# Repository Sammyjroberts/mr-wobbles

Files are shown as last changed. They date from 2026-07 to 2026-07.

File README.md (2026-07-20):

# Mr. Wobbles: a self-balancing two-wheel robot



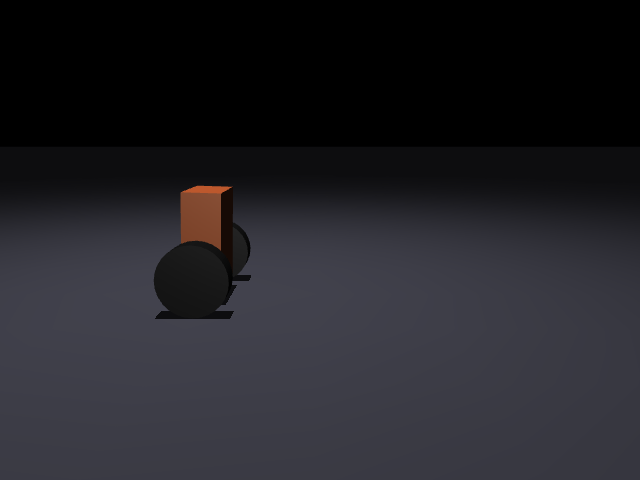
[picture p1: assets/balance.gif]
Mr. Wobbles balancing in simulation, taking a shove and recovering


*MuJoCo sim: the robot settles upright, takes a sideways shove at ~1.5 s, lunges ~27 cm to
catch itself, and drives back to center. Peak tilt during recovery ~3°. The controller is
the LQR designed in this repo, flying on the encoder + IMU signal path; render it yourself
with `scripts/record_gif.py`.*

Mr. Wobbles balancing on the bench (https://youtu.be/HPvMnAkXYeM)

*The real robot.* ▶ <a href="https://youtu.be/HPvMnAkXYeM" target="_blank" rel="noopener noreferrer">Watch on YouTube</a>

An inverted-pendulum robot built from first principles: the controller isn't tuned by
hand on the bench; it's **designed against the real machine**. Physical parameters are
derived from the printed chassis (mass and center of mass pulled straight from the STL)
plus component datasheets, fed into a linearized model, and an optimal (LQR) controller
is solved offline. The same parameters generate the MuJoCo validation plant, so the sim
and the design can never silently disagree.

Python does the physics and control design; the on-robot firmware (Rust + Embassy on an
RP2350 / Pico 2 W) balances the real robot and consumes the gains this repo produces — see
`firmware/`.

---

## The finding that shaped the design

The chassis looks tall and light, so intuition says the center of mass is high and the
robot falls slowly. It's the opposite. **Two 100 g gearmotors sit right on the wheel axle**,
and they drag the CoM down hard. Computed from the actual STL and datasheet masses:

| quantity | value |
|---|---|
| shell mass (from STL, PETG) | 176 g |
| pole / body mass | 511 g |
| total mass (with onboard battery) | 621 g |
| **L, CoM height above the axle**  | **50.8 mm** |

A naive guess put L near 90 mm; the real number is a fraction of that. A low CoM means a
short pendulum, which means a *fast-falling, twitchy* robot that demands a quicker control
loop and leaves less margin. The concrete design response is built into the chassis itself:
**carry the mass high.** The [v4 box-on-K-legs chassis](cad/gen_chassis.py) does this on
purpose — a boxy enclosure rides high on two braced K-legs, so the shell mass sits ~74 mm
above the axle and the electronics + battery nest inside it — so L lands at
**51 mm** instead of the ~29 mm of the old open flat plate, *even after* adding an 85 g battery
the tethered version never carried. Cutting the cord costs mass; standing it up on legs buys
back a longer, more forgiving pendulum. (These numbers regenerate from the STL via
`uv run balancer-params`, which also rewrites `outputs/physical_summary.txt`, so they can't go
stale against the printed chassis.)

This is the whole point of deriving parameters instead of guessing them: the hard part of
the problem was invisible until the numbers were real.

---

## How it works

```
robot_params.py   physical truth  →  mass, CoM, and L straight from the STL + datasheets
      │
      ├──────────────► lqr_design.py   linearize (finite-difference A, B) → Riccati → K
      │                                    4 gains for state [x, pitch, ẋ, pitch_rate]
      │
      └──────────────► plant.py        generate the wheels-on-ground MuJoCo contact model
                                           from the *same* params (validation, not design)
                                        │
                             balance.py │  real-time loop: u = −K · state, live viewer
                          evaluate.py   │  one rollout+metrics harness the tests + stats share
```

State reaches the controller the way the real robot will read it: **pitch/pitch-rate from
the IMU, position/velocity derived from the wheel encoders** (`x = wheel_angle · r`, not sim
ground truth, so slip shows up in the loop, as it will on hardware).

Two ideas do the heavy lifting:

- **Single source of truth.** Every physical number comes from `robot_params.py`. The gains
  `K` are solved at startup (never hardcoded) and the validation plant is generated from the
  same params (never a hand-written XML). Both of those were stale-parameter bugs earlier in
  the project; deriving everything from one place made that class of bug impossible.
- **The robot's job is trivial; the design is where the work is.** On hardware the controller
  is a single dot product, `u = −K · state`. All the intelligence lives in the offline
  Riccati solve that produces `K`.

---

## Results (in simulation)

Measured against the wheels-on-ground contact plant (`plant.py`), flying the LQR from
`lqr_design.py` on the encoder + IMU signal path. Every number below regenerates live from
the design via the same harness the CI tests assert on, so the table, the gates, and the
code can't drift apart: `uv run python scripts/report_stats.py`.

| metric | value | reading |
|---|---|---|
| open-loop unstable pole | \|z\| = **1.039** (> 1) | it genuinely wants to fall (gravity runaway) |
| closed-loop poles | \|z\| = 0.84, 0.98, 0.998, 0.998 | all inside the unit circle → **stabilized** |
| pitch recovery (from 3° tilt)  | back within 1° in **~0.07 s**  | the balancing loop is fast and aggressive |
| position re-centering | within ±10 mm in **~2.3 s** | slower, soft position loop (by design) |
| disturbance rejection | **2.2 N** shove → peak tilt **3.0°**, lunge ~20 cm | catches it and recovers |
| peak control effort | **0.042 N·m** of 0.31 N·m stall | ~**87 % torque headroom** at ideal sensors |
| encoder vs. true position | tracks within **~2 mm** while balancing | the sim-to-real signal path is faithful |

**The interesting finding: latency, not noise, is the enemy.** Sweeping to pessimistic
hardware (0.02 rad/s gyro noise + 4 ms control latency + PWM deadband), the *same* 2.2 N shove
drives peak tilt to **~32°** and momentarily **saturates the motors**, and isolating the knobs
shows it's almost entirely the **4 ms of loop latency**, not the noise. (The margin is thinner
than the tethered flat-plate build's ~19°: the untethered robot carries its own 85 g battery,
so it's heavier and a given shove hits harder — the cost of cutting the cord.) That's the
low-CoM finding cashing out: the pendulum is twitchy (fastest closed-loop mode ~6 ms), so a
fast, low-latency control loop is a **hard Phase-2 firmware requirement**, not a nicety. It
still recovers, but the ideal-sensor headroom is spent closing that gap.

**Phase-1 acceptance criterion.** With the IMU-only gains (no encoders, position feedback
zeroed) it balances but **drifts ~57 cm over 9 s**: quantified wander, not a bug. That's the
number to check the real robot against during Phase-1 bring-up: if it wanders faster than sim
predicts, something else is wrong.

The GIF up top is the ideal-sensor case: the 2.2 N shove and recovery.

---

## Quickstart

Uses [uv](https://docs.astral.sh/uv/).

```bash
uv sync                 # create the env + install deps

uv run balancer-params  # print physical numbers (mass, CoM, L); rewrite physical_summary.txt
uv run balancer-design  # solve LQR → gains K → outputs/Kc_real.npy, Kc_phase1.npy
uv run balancer-sim     # live balancing simulation (MuJoCo viewer)

uv run python scripts/report_stats.py   # the Results numbers, live from the design
uv run --group dev pytest               # the CI design gates (see below)
```

The console scripts are thin wrappers around `python -m balancer.sim.balance`, etc.

---

## Layout

```
src/balancer/
  params/robot_params.py   physical truth: mass/CoM/L from the STL + datasheet masses
  sim/lqr_design.py        linearize → LQR → K; mask_phase1() for the IMU-only gains
  sim/balance.py           real-time controller + viewer (u = −K · state); encoder state, PHASE switch
  sim/plant.py             wheels-on-ground contact model, generated from params
  sim/evaluate.py          one rollout + metrics harness (report_stats and tests both call it)
  paths.py                 resolves repo data dirs (cad/, outputs/)
tests/test_design.py       CI gates: stable, torque headroom, golden gains, encoder tracks truth
.github/workflows/         validate.yml, runs the gates on every push/PR
cad/balancer_chassis_v4.stl   printable box-on-K-legs chassis (PETG); mesh origin = wheel axle
cad/balancer_chassis_v4_top.stl / _bottom.stl   the two clamshell print halves
cad/gen_chassis.py            parametric generator for the box + K-legs
hardware/wiring_phase1.svg    Phase-1 wiring (balance on IMU, no encoders)
hardware/chassis_drawing.svg  dimensioned chassis drawing
scripts/record_gif.py         renders assets/balance.gif from the sim
scripts/report_stats.py       prints the Results numbers, live from the design
outputs/                      Kc_real.npy (Phase 2), Kc_phase1.npy (Phase 1), physical_summary.txt
```

---

## Hardware roadmap

- **Chassis (v4, box on K-legs):** the current design is a boxy enclosure riding high on two
  braced **K-legs** — the traditional self-balancer silhouette. Flat walls and a flat floor
  make it easy to seat a rectangular board + battery (four floor standoffs, a wire slot for the
  leads); the gearmotors are cradled in the feet, wheels out each side (`cad/gen_chassis.py` →
  `balancer_chassis_v4.stl`). It prints as a two-piece clamshell (`_top` / `_bottom`) split on
  the horizontal mid-plane, support-free; drop the electronics into the lower tub, cap with the
  upper half. It replaces the earlier open flat plate (v1/v2) and enclosed box (v3), and by
  standing the mass up high it's *more forgiving to balance* (L 29 → 51 mm) — see the finding
  above.
- **Power (cut the tether):** the bench build runs off a 12 V wall supply into the TB6612's
  `VM` screw terminal. To go free, the cheapest drop-in that matches the 12 V motors is a
  **3S LiPo** (11.1 V nominal, 12.6 V full; ~800–1300 mAh, ~80–110 g). Wire its XT30/XT60
  pigtail through a small slide switch into `VM`/`GND` (keep the common ground), and add a
  ~$3 LiPo low-voltage buzzer so you don't over-discharge it. The physical params already
  budget for an **85 g** pack (`M_BATTERY`) strapped high. Easier-but-bulkier alternative: a
  **3S 18650 pack** with a protection board (safer to charge, heavier). Avoid an 8×AA holder —
  ~230 g of sag-prone mass low down is the opposite of what this robot wants.
- **Phase 1 (IMU only):** Pico (USB) + TB6612 driver + 2 gearmotors + IMU (STEMMA QT).
  Balances on the IMU alone (gains in `outputs/Kc_phase1.npy`), so it drifts/wanders, with no
  position feedback. Simplest wiring, no level shifter. See `hardware/wiring_phase1.svg`.
- **Phase 2 (encoders):** wheel encoders for position hold, the validated flight config
  (`outputs/Kc_real.npy`, full-state feedback). Encoders run at 5 V and exceed the Pico's
  3.3 V limit, so this phase needs a **logic level shifter** (BSS138).
- **Firmware:** on-robot control loop in **Rust + Embassy** on the RP2350 (Pico 2 W): async
  tasks with a fixed-interval `Ticker` (500 Hz), I²C to the IMU, PWM + direction GPIO to the
  TB6612, and a hardware watchdog for crash recovery. Reads the gains `K` produced by
  `balancer-design`. Built and running — see `firmware/`.

**Build status:** the earlier open flat-plate build is **self-balancing on real hardware**
(Phase 1, IMU-only) — that's the clip up top. The **v4 box-on-K-legs chassis** is the current
design: derived through the same STL → params → gains pipeline and CI-gated in sim (the
Phase-2 encoder path is the default), printable as a clamshell, and the recommended next
build — not yet assembled on hardware. Next up: print the box, move onto an onboard
battery, then wheel encoders for Phase-2 position hold (`outputs/Kc_real.npy`).

---

## Notes

- `M_WHEEL` and `M_ELECTRONICS` in `robot_params.py` are estimates; refine if you weigh the
  parts. The motors and printed shell dominate the CoM and are both known precisely (the shell
  mass comes straight from the STL). `M_BATTERY` is the ~85 g 3S LiPo; drop it to 0 to model
  the tethered bench setup.
- `plant.py`'s pole inertia is lumped/approximate (mass and CoM height are exact; wheel spin
  inertia *is* modeled from the cylinder geoms); swap in a distributed pole inertia for tighter
  validation.
- `CONTROL_SIGN` / `ENC_SIGN` in `balance.py`: flip `CONTROL_SIGN` if the motors drive *into*
  the fall; `ENC_SIGN` sets which wheel-rotation direction is forward (pinned by
  `test_encoder_tracks_truth`). The usual first-run sign gotchas.
- The Results numbers are the encoder-path, ideal-sensor case. Real hardware lives closer to
  the realistic sweep, so budget for the latency finding.

MIT licensed.

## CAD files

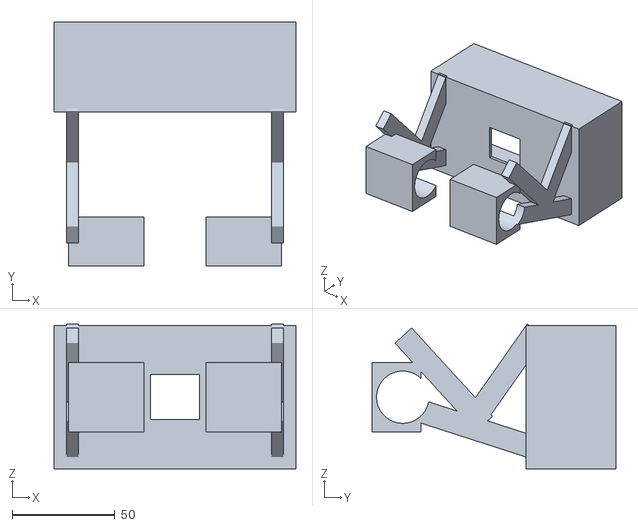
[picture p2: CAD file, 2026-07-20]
cad/balancer_chassis_v4_bottom.stl
118.0 x 119.0 x 70.7

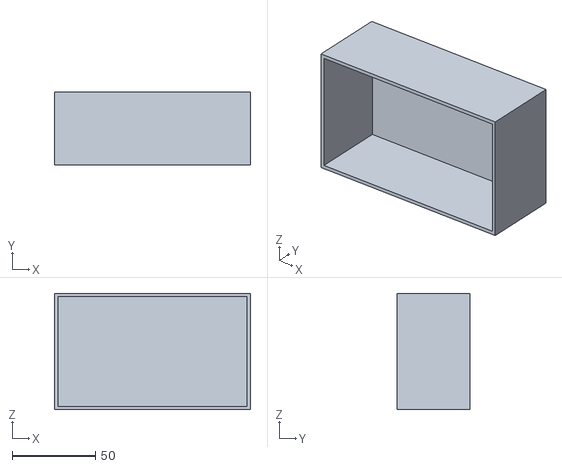
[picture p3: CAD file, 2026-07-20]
cad/balancer_chassis_v4_top.stl
118.0 x 44.0 x 70.0

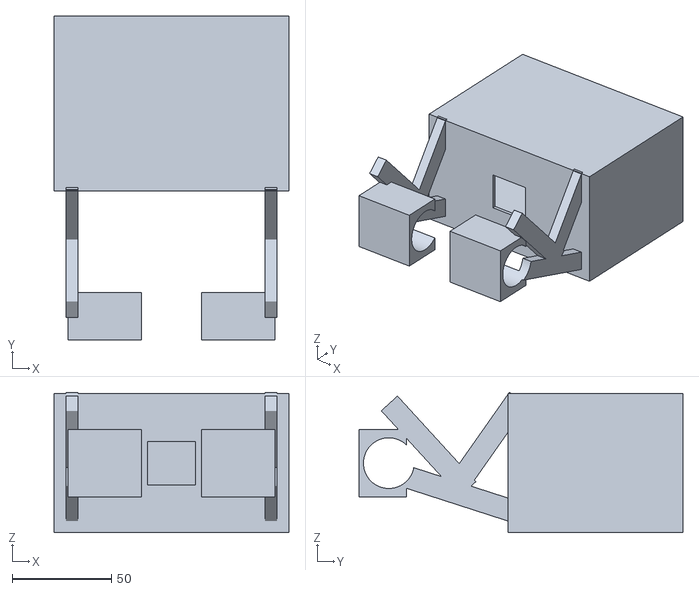
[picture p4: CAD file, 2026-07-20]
cad/balancer_chassis_v4.stl
118.0 x 163.0 x 70.7

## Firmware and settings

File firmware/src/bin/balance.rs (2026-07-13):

#![no_std]
#![no_main]

//! balance — Phase-1 (IMU-only) self-balancing controller for Mr. Wobbles.
//!
//! Control law (from src/balancer/sim/balance.py, gains from outputs/Kc_phase1.npy):
//!     state  = [x, pitch, x_dot, pitch_rate]   (SI: rad, rad/s)
//!     force  = -K . state                       (desired cart force, N)
//!     torque = force * wheel_radius             (N*m) -> PWM duty
//! Phase 1 has no encoders, so x and x_dot are 0 and only the pitch / pitch_rate
//! gains act. It BALANCES but WANDERS (no position hold) — expected until encoders.
//!
//! Pitch comes from the IMU via the mount config in imu_map.rs (fused with a
//! complementary filter). +pitch = nose forward, upright = 0.
//!
//! SAFETY / behavior:
//!   * Boots DISARMED (motors off, STBY low). Arms only after it's held within
//!     ARM_ANGLE of upright for ARM_HOLD. So: plug in 12V, stand it up -> it goes.
//!   * If |pitch| exceeds FALL_ANGLE it DISARMS (motors off) and re-arms when
//!     stood back up.
//!   * Output is capped at MAX_DUTY.
//!
//! >>> FIRST TEST HELD IN HAND <<< The motor-direction signs below are unverified.
//! If CONTROL_SIGN is wrong the robot drives itself OVER when armed. Hold it, let
//! it arm, tip it slightly forward, and confirm the wheels spin to drive FORWARD
//! (under the lean). If they drive backward, flip CONTROL_SIGN. If the two wheels
//! fight each other, flip one of MOTOR_A_SIGN / MOTOR_B_SIGN.
//!
//! Run: cargo run --bin balance --release

use defmt::*;
use embassy_executor::Spawner;
use embassy_rp::bind_interrupts;
use embassy_rp::block::ImageDef;
use embassy_rp::gpio::{Level, Output};
use embassy_rp::i2c::{self, I2c};
use embassy_rp::peripherals::I2C0;
use embassy_rp::pwm::{Config as PwmConfig, Pwm};
use embassy_rp::watchdog::Watchdog;
use embassy_time::{Duration, Ticker, Timer};
use embedded_hal_async::i2c::I2c as _;
use {defmt_rtt as _, panic_probe as _};

#[path = "../imu_map.rs"]
mod imu_map;

// Gantry telemetry: opt-in, fully compiled out without `--features telemetry`.
#[cfg(feature = "telemetry")]
#[path = "../telemetry.rs"]
mod telemetry;

#[link_section = ".start_block"]
#[used]
static IMAGE_DEF: ImageDef = ImageDef::secure_exe();

bind_interrupts!(struct Irqs {
    I2C0_IRQ => i2c::InterruptHandler<I2C0>;
});

// Separate binding for the USB peripheral, only when telemetry is enabled.
#[cfg(feature = "telemetry")]
bind_interrupts!(struct UsbIrqs {
    USBCTRL_IRQ => embassy_rp::usb::InterruptHandler<embassy_rp::peripherals::USB>;
});

// ===================== Controller (Phase 1, IMU-only) =====================
// From outputs/Kc_phase1.npy = [0, -19.443, 0, -1.412] on [x, pitch, x_dot, pitch_rate].
const K_PITCH: f32 = -19.443; // N per rad
const K_PITCH_RATE: f32 = -1.412; // N per (rad/s)
const WHEEL_RADIUS_M: f32 = 0.035;
const STALL_TORQUE_NM: f32 = 0.314; // maps commanded torque -> PWM fraction

// ===================== Signs — VERIFY ON THE BENCH (held) =====================
// Drive direction lives in the mount config (imu_map::DRIVE_SIGN).
const MOTOR_A_SIGN: f32 = 1.0; // flip if LEFT wheel rolls opposite the robot's forward
const MOTOR_B_SIGN: f32 = 1.0; // flip if RIGHT wheel rolls opposite

// ===================== Loop / safety / filter =====================
const LOOP_HZ: u64 = 500; // 2 ms, matches the sim timestep; IMU runs 833 Hz so samples are fresh
const DT: f32 = 1.0 / LOOP_HZ as f32;
const ALPHA: f32 = 0.99; // complementary filter, retuned for 500 Hz (~0.2 s time constant)
const ARM_ANGLE_DEG: f32 = 4.0; // within this of upright to arm
const ARM_HOLD_CYCLES: u32 = (LOOP_HZ as u32) / 2; // ...held ~0.5 s
const FALL_ANGLE_DEG: f32 = 30.0; // past this = fallen -> disarm
const MAX_DUTY: f32 = 0.60; // raised from 0.30 after the gyro-sign fix — it was saturating 39% of the time
const DEADBAND_DUTY: f32 = 0.12; // feedforward past motor stiction so small corrections still move the wheels (tune to your motors)
const CONTROL_DEADZONE: f32 = 0.04; // below this duty = coast (ignore sensor noise near upright, don't buzz the wheels)
const DEG2RAD: f32 = core::f32::consts::PI / 180.0;

// PWM: slice 0 drives GP16 (A) + GP17 (B). TOP=7499 -> ~20 kHz.
const PWM_TOP: u16 = 7499;

// LSM6DSOX registers.
const ADDR: u8 = 0x6A;
const EXPECTED_WHO_AM_I: u8 = 0x6C;
const REG_WHO_AM_I: u8 = 0x0F;
const REG_CTRL1_XL: u8 = 0x10;
const REG_CTRL2_G: u8 = 0x11;
const REG_CTRL3_C: u8 = 0x12;
const REG_OUTX_L_G: u8 = 0x22;
const CTRL1_XL_833HZ_4G: u8 = 0x78; // 833 Hz ODR, +-4 g (fresh samples for the 500 Hz loop)
const CTRL2_G_833HZ_500DPS: u8 = 0x74; // 833 Hz ODR, +-500 dps
const CTRL3_C_BDU_IFINC: u8 = 0x44;
const ACC_SENS_G_PER_LSB: f32 = 0.122e-3;
const GYR_SENS_DPS_PER_LSB: f32 = 17.50e-3;

/// Set one TB6612 channel from a signed duty in [-1,1]; returns the PWM compare.
/// duty>0 => IN1 high / IN2 low (forward); duty<0 => reverse; sign picks direction.
fn drive(duty: f32, in1: &mut Output<'static>, in2: &mut Output<'static>) -> u16 {
    let mag = if duty.abs() > MAX_DUTY { MAX_DUTY } else { duty.abs() };
    if duty >= 0.0 {
        in1.set_high();
        in2.set_low();
    } else {
        in1.set_low();
        in2.set_high();
    }
    (mag * (PWM_TOP as f32 + 1.0)) as u16
}

#[embassy_executor::main]
async fn main(_spawner: Spawner) {
    let p = embassy_rp::init(Default::default());
    info!("balance: booting (Phase 1, IMU-only)");

    // --- Gantry telemetry: init pipeline + spawn the USB-CDC drain task (feature-gated) ---
    #[cfg(feature = "telemetry")]
    {
        telemetry::init();
        let usb_driver = embassy_rp::usb::Driver::new(p.USB, UsbIrqs);
        _spawner.must_spawn(telemetry::telemetry_usb_task(usb_driver));
        info!("telemetry: gantry-tlm up, USB-CDC streaming as \"gantry-tlm\"");
    }

    // --- Motors: start fully disabled (STBY low, all pins low, 0 duty) ---
    let mut stby = Output::new(p.PIN_22, Level::Low);
    let mut ain1 = Output::new(p.PIN_18, Level::Low);
    let mut ain2 = Output::new(p.PIN_19, Level::Low);
    let mut bin1 = Output::new(p.PIN_20, Level::Low);
    let mut bin2 = Output::new(p.PIN_21, Level::Low);
    let mut pwm_cfg = PwmConfig::default();
    pwm_cfg.top = PWM_TOP;
    pwm_cfg.compare_a = 0;
    pwm_cfg.compare_b = 0;
    let mut pwm = Pwm::new_output_ab(p.PWM_SLICE0, p.PIN_16, p.PIN_17, pwm_cfg.clone());

    // --- IMU on I2C0 (GP4/GP5), 400 kHz for the control-loop read rate ---
    let mut i2c_cfg = i2c::Config::default();
    i2c_cfg.frequency = 400_000;
    let mut i2c = I2c::new_async(p.I2C0, p.PIN_5, p.PIN_4, Irqs, i2c_cfg);
    loop {
        let mut who = [0u8; 1];
        match i2c.write_read(ADDR, &[REG_WHO_AM_I], &mut who).await {
            Ok(()) if who[0] == EXPECTED_WHO_AM_I => break,
            Ok(()) => error!("WHO_AM_I=0x{:02X} (want 0x{:02X})", who[0], EXPECTED_WHO_AM_I),
            Err(e) => error!("IMU not acking: {:?} (check wiring). retrying...", e),
        }
        Timer::after(Duration::from_secs(1)).await;
    }
    unwrap!(i2c.write(ADDR, &[REG_CTRL3_C, CTRL3_C_BDU_IFINC]).await);
    unwrap!(i2c.write(ADDR, &[REG_CTRL1_XL, CTRL1_XL_833HZ_4G]).await);
    unwrap!(i2c.write(ADDR, &[REG_CTRL2_G, CTRL2_G_833HZ_500DPS]).await);
    info!(
        "IMU up. gains: Kp={=f32} Kd={=f32}. signs: drive={=f32} A={=f32} B={=f32}. Hold UPRIGHT to arm.",
        K_PITCH, K_PITCH_RATE, imu_map::DRIVE_SIGN, MOTOR_A_SIGN, MOTOR_B_SIGN
    );

    // --- Watchdog: auto-recover from a crash ---
    // If the control loop ever hangs, panics, or HardFaults, it stops feeding this
    // timer and the RP2350 resets itself — rebooting straight back into balancing
    // from flash instead of parking dead. Started after IMU bring-up so the WHO_AM_I
    // retry loop can't trip it; fed at the top of every control cycle (2 ms).
    let mut watchdog = Watchdog::new(p.WATCHDOG);
    watchdog.start(Duration::from_millis(500));

    // --- Seed the complementary filter from the accelerometer ---
    let (ax, ay, az, _, _, _) = read_all(&mut i2c).await;
    let mut pitch = imu_map::pitch_deg(ax, ay, az); // deg

    let mut armed = false;
    let mut upright_cycles: u32 = 0;
    let mut log_div: u32 = 0;
    // Telemetry decimator: the loop runs at 500 Hz; stream at ~50 Hz (every 10th cycle).
    #[cfg(feature = "telemetry")]
    let mut tlm_div: u32 = 0;
    let mut ticker = Ticker::every(Duration::from_hz(LOOP_HZ));

    loop {
        ticker.next().await;
        watchdog.feed(); // pet the watchdog; a hang past 500 ms resets & reboots
        let (ax, ay, az, gx, gy, gz) = read_all(&mut i2c).await;

        // --- Pitch: complementary filter (deg), + gyro pitch rate (deg/s) ---
        let pitch_acc = imu_map::pitch_deg(ax, ay, az);
        let pitch_rate = imu_map::pitch_rate_dps(gx, gy, gz);
        pitch = ALPHA * (pitch + pitch_rate * DT) + (1.0 - ALPHA) * pitch_acc;

        // Telemetry mirrors of the controller outputs (stay 0 while disarmed). cfg-gated so
        // the plain build is byte-identical — these lines don't exist without the feature.
        #[cfg(feature = "telemetry")]
        let mut tlm_force = 0.0f32;
        #[cfg(feature = "telemetry")]
        let mut tlm_duty = 0.0f32;

        // --- Arm / disarm state machine ---
        let upright = pitch.abs() < ARM_ANGLE_DEG;
        let fallen = pitch.abs() > FALL_ANGLE_DEG;
        if !armed {
            upright_cycles = if upright { upright_cycles + 1 } else { 0 };
            if upright_cycles >= ARM_HOLD_CYCLES {
                armed = true;
                stby.set_high(); // enable the driver
                info!("ARMED — balancing. (pitch={=f32}deg)", pitch);
            }
        } else if fallen {
            armed = false;
            upright_cycles = 0;
            // Coast everything off.
            ain1.set_low();
            ain2.set_low();
            bin1.set_low();
            bin2.set_low();
            pwm_cfg.compare_a = 0;
            pwm_cfg.compare_b = 0;
            pwm.set_config(&pwm_cfg);
            stby.set_low(); // disable driver
            warn!("FALL detected (pitch={=f32}deg) — DISARMED. Stand it up to re-arm.", pitch);
        }

        // --- Control law (only when armed) ---
        if armed {
            let pitch_rad = pitch * DEG2RAD;
            let rate_rad = pitch_rate * DEG2RAD;
            // force = -K.state (Phase 1: x, x_dot = 0). torque = force * r.
            let force = -(K_PITCH * pitch_rad + K_PITCH_RATE * rate_rad); // N
            let torque = force * WHEEL_RADIUS_M; // N*m
            let mut duty = torque / STALL_TORQUE_NM; // -> PWM fraction
            duty *= imu_map::DRIVE_SIGN;
            // Near-upright deadzone: ignore tiny commands (mostly sensor noise) so the
            // wheels don't buzz back and forth around vertical. Real corrections (above
            // the deadzone) get a feedforward kick past gearmotor stiction.
            if duty.abs() < CONTROL_DEADZONE {
                duty = 0.0;
            } else {
                duty += duty.signum() * DEADBAND_DUTY;
            }
            if duty > MAX_DUTY {
                duty = MAX_DUTY;
            } else if duty < -MAX_DUTY {
                duty = -MAX_DUTY;
            }
            pwm_cfg.compare_a = drive(duty * MOTOR_A_SIGN, &mut ain1, &mut ain2);
            pwm_cfg.compare_b = drive(duty * MOTOR_B_SIGN, &mut bin1, &mut bin2);
            pwm.set_config(&pwm_cfg);

            // Capture the commanded force/duty for telemetry (send happens below).
            #[cfg(feature = "telemetry")]
            {
                tlm_force = force;
                tlm_duty = duty;
            }

            log_div += 1;
            if log_div >= LOOP_HZ as u32 / 20 {
                // ~20 Hz
                log_div = 0;
                info!("bal pitch={=f32}deg rate={=f32}dps duty={=f32}", pitch, pitch_rate, duty);
            }
        } else {
            // Disarmed: log slowly so you can see it waiting.
            log_div += 1;
            if log_div >= LOOP_HZ as u32 {
                log_div = 0;
                info!("disarmed, waiting for upright. pitch={=f32}deg", pitch);
            }
        }

        // --- Telemetry: stream at ~50 Hz (decimated from the 500 Hz loop) ---
        #[cfg(feature = "telemetry")]
        {
            tlm_div += 1;
            if tlm_div >= LOOP_HZ as u32 / 50 {
                tlm_div = 0;
                telemetry::send_imu(pitch, pitch_rate);
                telemetry::send_drive(tlm_duty * MOTOR_A_SIGN, tlm_duty * MOTOR_B_SIGN);
                telemetry::send_balance(tlm_force, armed);
            }
        }
    }
}

async fn read_all(i2c: &mut I2c<'static, I2C0, i2c::Async>) -> (f32, f32, f32, f32, f32, f32) {
    let mut raw = [0u8; 12];
    let _ = i2c.write_read(ADDR, &[REG_OUTX_L_G], &mut raw).await;
    let gx = i16::from_le_bytes([raw[0], raw[1]]) as f32 * GYR_SENS_DPS_PER_LSB;
    let gy = i16::from_le_bytes([raw[2], raw[3]]) as f32 * GYR_SENS_DPS_PER_LSB;
    let gz = i16::from_le_bytes([raw[4], raw[5]]) as f32 * GYR_SENS_DPS_PER_LSB;
    let ax = i16::from_le_bytes([raw[6], raw[7]]) as f32 * ACC_SENS_G_PER_LSB;
    let ay = i16::from_le_bytes([raw[8], raw[9]]) as f32 * ACC_SENS_G_PER_LSB;
    let az = i16::from_le_bytes([raw[10], raw[11]]) as f32 * ACC_SENS_G_PER_LSB;
    (ax, ay, az, gx, gy, gz)
}

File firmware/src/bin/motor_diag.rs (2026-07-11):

#![no_std]
#![no_main]

//! motor_diag — steady-state TB6612 diagnostic for a "motor won't move" bringup.
//!
//! Unlike motor_test (which cycles), this drives channel A FORWARD at 100% and
//! HOLDS it, so every control line sits at a stable DC level you can probe with
//! a multimeter. Expected readings (black probe on a common GND) while running:
//!
//!   VM   (TB6612 motor supply) .... ~12 V     <- your battery/supply + polarity
//!   VCC  (TB6612 logic supply) .... ~3.3 V     <- MUST be powered or nothing works
//!   STBY (GP22) ................... ~3.3 V
//!   AIN1 (GP18) ................... ~3.3 V
//!   AIN2 (GP19) ................... ~0 V
//!   PWMA (GP16) ................... ~3.3 V      (100% duty = held high)
//!   AO1 <-> AO2 (motor terminals) . ~11-12 V    <- this is what actually spins it
//!
//! Diagnosis:
//!   * VCC = 0            -> logic rail not connected. Wire TB6612 VCC to Pico 3V3.
//!   * a control pin = 0 AT THE TB6612 but 3.3 V at the Pico pin -> broken/missing wire.
//!   * all inputs correct, VM=12, VCC=3.3, but AO1-AO2 = 0 -> no common GND, or dead driver.
//!   * AO1-AO2 = 12 V but motor still still -> motor leads not making contact / dead motor.
//!
//! GROUND CHECK (do this with power OFF, meter in continuity/ohms):
//!   Pico GND <-> TB6612 GND must beep/read ~0 ohm. If not, that's the fault.
//!
//! Run: cargo run --bin motor_diag --release

use defmt::*;
use embassy_executor::Spawner;
use embassy_rp::block::ImageDef;
use embassy_rp::gpio::{Level, Output};
use embassy_rp::pwm::{Config as PwmConfig, Pwm};
use embassy_time::{Duration, Timer};
use {defmt_rtt as _, panic_probe as _};

#[link_section = ".start_block"]
#[used]
static IMAGE_DEF: ImageDef = ImageDef::secure_exe();

const PWM_TOP: u16 = 7499; // ~20 kHz

#[embassy_executor::main]
async fn main(_spawner: Spawner) {
    let p = embassy_rp::init(Default::default());
    info!("motor_diag: holding channel A FORWARD @ 100% for steady-state probing");

    // Enable driver.
    let mut _stby = Output::new(p.PIN_22, Level::High); // STBY = HIGH -> enabled
    // Channel A direction: FORWARD = AIN1 high, AIN2 low.
    let mut _ain1 = Output::new(p.PIN_18, Level::High);
    let mut _ain2 = Output::new(p.PIN_19, Level::Low);

    // PWMA (GP16) held at 100% duty.
    let mut cfg = PwmConfig::default();
    cfg.top = PWM_TOP;
    cfg.compare_a = PWM_TOP + 1; // 100% -> output always high
    cfg.compare_b = 0;
    let _pwm = Pwm::new_output_ab(p.PWM_SLICE0, p.PIN_16, p.PIN_17, cfg);

    info!("STBY=GP22=HIGH  AIN1=GP18=HIGH  AIN2=GP19=LOW  PWMA=GP16=100%");
    info!("Probe now: VM~12V, VCC~3.3V, STBY/AIN1/PWMA~3.3V, AIN2~0V, motor terminals ~12V");
    info!("If motor terminals read 0V with inputs correct: check COMMON GROUND (Pico GND <-> TB6612 GND).");

    // Hold forever; heartbeat so you know it's alive.
    let mut n = 0u32;
    loop {
        Timer::after(Duration::from_secs(2)).await;
        n += 1;
        info!("still holding FORWARD @ 100% ({=u32}s)", n * 2);
    }
}

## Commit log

2026-06-28 Initial commit: Mr. Wobbles self-balancing robot
    Two-wheel self-balancing robot as an installable uv package:
    - src/balancer: params (STL-derived physics), LQR design, MuJoCo sim
    - cad/hardware: printable chassis + wiring/drawings
    - console scripts: balancer-params / balancer-design / balancer-sim
    [balancer_chassis_v1.stl]
2026-06-28 Fix stale-K split: design gains from current params at sim startup
    balance.py held hardcoded gains for the old 92mm-CoM guess while
    lqr_design computed the real 28mm-CoM K — two producers, one stale.
    Now balance.py designs K via the same compute_K()/Q/R as lqr_design,
    so the sim can never fly stale gains. Also source WHEEL_RADIUS from
    robot_params.WHEEL_R, and give Kc_real.npy one home in paths.py.
2026-06-28 Generate contact plant from robot_params (kills phantom-plant validation)
    The hand-written balancer.xml held the old assumed params (body 0.6kg,
    CoM 0.11m), so balance.py was validating K against a phantom robot, not
    the real one. Replace it with plant.py: plant_xml() builds the full 3D
    wheels-on-ground MJCF from robot_params, so the validation plant always
    carries the real mass + CoM height (L=27.7mm) — same single-source-of-
    truth fix we made for K. Static balancer.xml removed.
    Verified on the real plant: controller on settles from a 7deg kick;
    controller off topples (178deg). Adds `balancer-plant` to print the XML.
2026-07-04 fix chassis gen
    [balancer_chassis_v2.stl]
2026-07-04 drop thickness to 4mm
2026-07-04 update with real chassis thickness
    [balancer_chassis_v2.stl]
2026-07-08 Harden sim: encoder signal path, CI design gates, Phase-1 controller
    Move the sim onto the real hardware signal path and lock the design behind
    automated release gates, so the gains can't reach the robot out of spec.
    Controller
    - Fly position/velocity from the wheel encoders (x = wheel_angle * r), the exact
    path the RP2040 firmware will use, instead of sim ground truth. Tracks truth to
    ~2 mm while balancing; slip now shows up in the loop.
    - Add a PHASE switch and mask_phase1(): Phase-1 (IMU only, no encoders) zeros the
    position gains and balances-but-wanders (~28 cm / 9 s). Saved to Kc_phase1.npy
    as the Phase-1 bring-up acceptance criterion.
    Evaluation + CI
    - evaluate.py: one rollo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
2026-07-11 Add Rust/Embassy firmware for RP2350 (Pico 2 W)
    Phase-1 (IMU-only) self-balancing firmware plus bring-up test binaries,
    targeting thumbv8m.main-none-eabihf with embassy-rp, defmt/RTT over a debug probe.
    Binaries (src/bin/):
    - balance : IMU-only balance controller (Kc_phase1 gains, complementary
    filter, 500 Hz loop, arm-on-upright + fall-cutoff safety)
    - imu_test : LSM6DSOX WHO_AM_I + bus scan + accel/gyro/pitch stream
    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
2026-07-13 feat(firmware): integrate Gantry telemetry over USB-CDC (opt-in)
    Add gantry-tlm device telemetry to the balancer, gated behind a default-off
    `telemetry` feature so the plain build is byte-identical (verified: release
    .text/.data/.bss unchanged at 15252/56/1756).
    - Cargo.toml: optional gantry-tlm (path dep, default-features=false),
    embassy-usb 0.5, static_cell; `telemetry` feature wires gantry-tlm/enabled.
    - telemetry.rs (new, fully cfg-gated): Imu/Drive/Balance packets mirroring the
    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
2026-07-13 build(firmware): switch gantry-tlm to git dependency
    Any clone builds without a sibling gantry checkout; local SDK hacking
    goes through a [patch] override instead (documented inline).
2026-07-13 chore: add gantry MCP config for Claude Code
    Sessions opened in this repo auto-discover the local Gantry Edge
    telemetry server (localhost:4780/mcp) - ask Claude what the robot
    did while the bench is hot.
2026-07-13 build(firmware): re-pin gantry-tlm after upstream history rewrite
2026-07-13 fix(firmware): correct inverted gyro sign + add watchdog + raise duty cap
    imu_map::ROBOT_AXLE sign -1 -> +1. The gyro pitch-rate was inverted vs the true
    angular velocity (measured corr -0.66 with d(raw pitch)/dt on live telemetry),
    which corrupted the complementary-filter estimate AND made the D-term anti-damping
    -- the root cause of the limit cycle. After the fix the robot self-balances.
    Also:
    - hardware watchdog (500 ms): a hung/panicked control loop self-resets and reboots
    into balancing from flash instead of parking dead.
    - MAX_DUTY 0.30 -> 0.60 (was saturating the cap ~39% of the time).
    [balance.rs]
2026-07-19 feat(chassis): v3 enclosed-box chassis + onboard 3S LiPo
    Replace the open flat backplate (v1/v2) with a "normal" self-balancing
    form: a closed box that seats the electronics inside, riding on two wheels
    that mount to bulkheads underneath. Snap-on lid; board on floor standoffs;
    battery straps high on the inside back wall; motor leads run up through a
    floor pass-through.
    The mesh origin is now the wheel axle, so a point's Y coordinate is directly
    its height above the axle (robot_params drops the old plate-offset hack).
    Mounting mass high is the design response to the project's own finding (low
    CoM -> twitchy): L rises 29.3 -> 35.1 mm even after adding an 85 g battery
    the tethered build never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
    [balancer_chassis_v1.stl, balancer_chassis_v2.stl, balancer_chassis_v3.stl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]
2026-07-19 feat(chassis): v4 barrel-on-legs chassis with a face
    Pivot the chassis form to the friendly "barrel on two splayed legs" look:
    a hollow barrel body (face embossed on the front cap) held up high on four
    rods that carry the gearmotors + wheels in the feet. Prints as a two-piece
    clamshell split through the axis (support-free); electronics + battery nest
    in the lower half, leads run up a wire slot, top clips on.
    Same STL -> params -> gains pipeline as before (mesh origin = wheel axle).
    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
    [balancer_chassis_v3.stl, balancer_chassis_v4.stl, balancer_chassis_v4_bottom.stl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]
2026-07-20 feat(chassis): rotate barrel across the top, K-shaped braced legs
    Restyle v4 to the traditional two-wheel-balancer silhouette: the barrel now
    lies ACROSS the top with its axis parallel to the wheel axle (rotated 90 deg
    from the nose-forward orientation), face embossed on the front curve. The two
    straight splayed rods are replaced by braced K-legs -- a spine plus two
    diagonals meeting at a knee -- one flat truss per side, feet straddling the
    axle. Body rides higher on the longer legs.
    Same STL -> params -> gains pipeline. Standing the mass up this high pushes L
    to 49.9 mm (vs 41 for the earlier barrel, 29 for the flat plate); all 9 CI
    design gates still pass with ~86% torque headroom, realis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
    [balancer_chassis_v4.stl, balancer_chassis_v4_bottom.stl, balancer_chassis_v4_top.stl]
2026-07-20 feat(chassis): square box body on the K-legs, drop the face
    Swap the barrel body for a boxy enclosure on the same braced K-legs, and
    remove the face. Flat walls + a flat floor make it easy to seat a rectangular
    board and battery (four floor standoffs + a wire slot); still prints as a
    two-piece clamshell split at box mid-height, electronics into the lower tub.
    Same STL -> params -> gains pipeline. L = 50.8 mm; all 9 CI design gates pass
    with ~86% torque headroom. The box is heavier than the barrel (176 g shell,
    621 g total), so the realistic-sweep shove sits a touch higher (~32 deg, still
    under the 35 deg topple gate) -- documented in the README. Regenerated gains +
    summary; updated README a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
    [balancer_chassis_v4.stl, balancer_chassis_v4_bottom.stl, balancer_chassis_v4_top.stl]
